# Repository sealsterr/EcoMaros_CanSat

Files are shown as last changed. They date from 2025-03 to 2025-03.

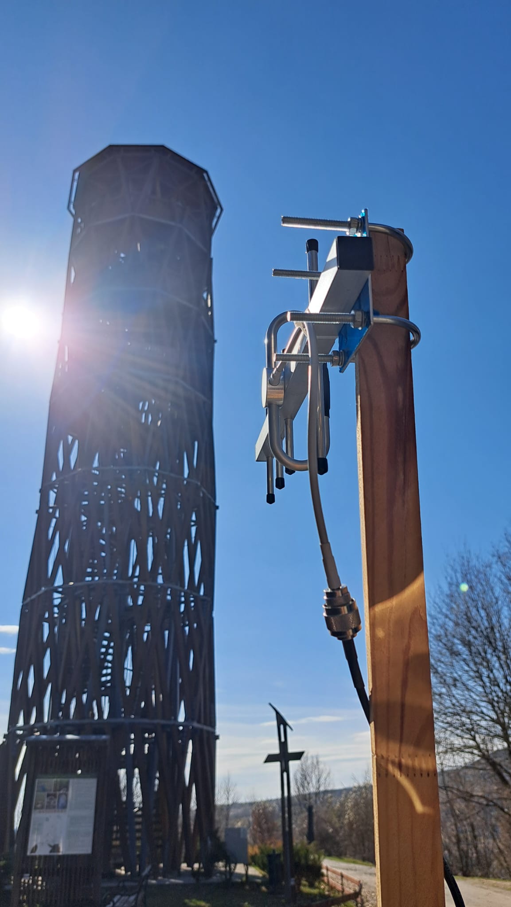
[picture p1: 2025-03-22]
Testing/final_test/image_5.jpeg

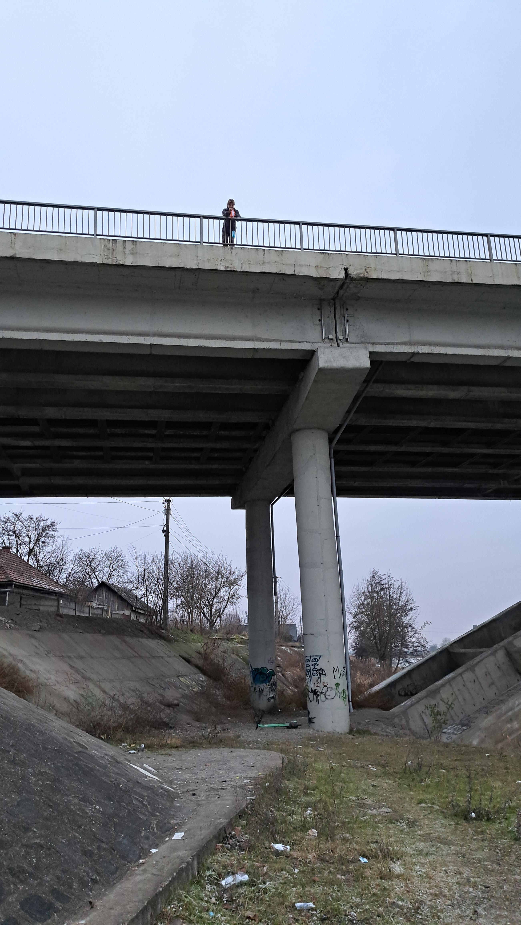
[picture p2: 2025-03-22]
Testing/parachute_test/20250118_162305(0).jpg

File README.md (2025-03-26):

# EcoMaros CanSat Project





Our team's project for the 2025 CanSat Hungary Competition.

## Table of Contents
- [Project Overview](#project-overview)
- [System Architecture](#system-architecture)
- [Hardware Components](#hardware-components)
- [Software Architecture](#software-architecture)
- [Testing](#testing)
- [Contributors](#contributors)
- [License](#license)

---

# Project Overview

## 🌍 Introduction
EcoMaros is a CanSat project developed for the European Space Agency’s CanSat competition. Our mission was to design, build, and launch a fully functional satellite the size of a soda can, carrying out both a **primary mission** (measuring atmospheric temperature and pressure) and a **secondary mission** (environmental air quality analysis).

Our CanSat was launched from a rocket, reaching an altitude of approximately **1 km** before descending via parachute while continuously transmitting data to our ground station. The data collected was analyzed to extract valuable scientific insights and improve future small-satellite designs.

## 🛠️ Mission Objectives

### ✅ **Primary Mission:**
- **Measure atmospheric temperature and pressure** throughout the descent.
- **Log and transmit real-time data** to the ground station.
- **Compare results with trusted meteorological sources** to ensure accuracy.

### 🌿 **Secondary Mission:**
- **Analyze air quality parameters** by measuring pollutants such as CO, CO₂, NO₂, and VOC levels.
- **Monitor altitude-based variations** in air quality and correlate with temperature/pressure.
- **Evaluate sensor efficiency** and compare with standardized environmental datasets.
- **Capture high-resolution video footage** during descent using an onboard camera, providing visual data to complement sensor readings and assist in post-mission analysis.

## 🛰️ Technical Summary

Our CanSat consisted of **three primary systems**:

1. **The CanSat** (the satellite itself):
   - Housed **sensors**, **microcontrollers**, and **power systems**.
   - Collected, processed, and transmitted environmental data.
   - Designed to survive high-G forces and impact upon landing.

2. **The Recovery System** (parachute):
   - Ensured **stable descent** for optimal data collection.
   - Tested under real-world conditions.

3. **The Ground Station** (communication and data reception):
   - Received **live telemetry** from the CanSat.
   - Used **LoRa communication** at 868 MHz.
   - Displayed data in **real-time dashboards** for analysis.

## 🔬 Innovation & Unique Features

- **Hybrid Communication System:** Combined LoRaWAN for real-time transmission with onboard SD card storage for redundancy.
- **Optimized Air Quality Sensor Placement:** Minimized contamination and external interferences.
- **Advanced Software Architecture:** Supported real-time data visualization and predictive modeling.
- **Robust Mechanical Design:** Impact-resistant casing, secure wiring, and heat-resistant materials ensured durability.

## 🚀 Development Phases

1. **Design & Planning:** Component selection, CAD modeling, and circuit design.
2. **Prototype Assembly:** Initial hardware integration and software development.
3. **Ground Testing:** Component-level and full-system tests, including **environmental, communication, and structural validation**.
4. **Flight Preparation:** Calibration, parachute testing, and mission simulations.
5. **Launch & Data Analysis:** Real-world deployment, telemetry collection, and post-flight analysis.

---

# System Architecture

The EcoMaros CanSat consists of multiple integrated subsystems, each playing a critical role in the mission. The architecture is designed to ensure efficient data collection, processing, and communication while maintaining structural integrity during descent.

## 🖥️ Block Diagram

The following diagram illustrates the overall architecture of the CanSat system, highlighting interactions between subsystems:

diagram

## 🛰️ Subsystem Overview

### 1️⃣ **Power Management System**
The CanSat operates using **two independent power sources**:
- **2000mAh 3.7V LiPo Battery:** Supplies power to the microcontroller, sensors, and radio transmitter.
- **1000mAh 3.7V LiPo Battery:** Dedicated to powering the onboard camera.
A **step-up voltage booster** (3.7V → 5V) ensures that the camera receives stable voltage for optimal performance.

**Key Features:**
- Dual power system ensures redundancy and extended operation time.
- Low-power microcontroller for optimized energy consumption.
- Integrated master switch to safely power the CanSat on/off.

### 2️⃣ **Microcontroller & Processing Unit**
The heart of the CanSat is the **Adafruit Feather M0 Adalogger**, which:
- Manages sensor data acquisition.
- Controls power distribution.
- Handles real-time telemetry transmission.
- Logs data onto the onboard SD card.

microcontroller

### 3️⃣ **Sensor Suite**
EcoMaros is equipped with a **diverse set of sensors** to ensure comprehensive environmental monitoring:

| Sensor | Function | Model |
|---|---|---|
| **Barometric Pressure & Temperature Sensor** | Measures altitude and air temperature | BMP280 |
| **Air Quality Sensor** | Detects pollutants (CO₂, NO₂, VOCs) | MQ135 |
| **Accelerometer & Gyroscope** | Measures orientation, tilt, and G-forces | MPU6050 |
| **GPS Module** | Tracks real-time location and altitude | DFRobot Gravity GNSS |
| **Camera** | Records footage during the mission | ESP32 CAM |

sensors
camera

**Data Collection & Processing:**
- All sensor data is processed **every 200ms** and stored in CSV format.
- In case of radio failure, the data is alos logged to an **onboard SD card** for post-flight analysis.
- The onboard motion-detecting camera captures video data separately.

### 4️⃣ **Communication System**
The CanSat transmits real-time telemetry data using an **RFM69HCW 868 MHz radio module**, connected to a **5 dBi dipole antenna**.

**Communication Flow:**
1. Sensor data is processed by the microcontroller.
2. Data packets are formatted and transmitted via the **RFM69HCW module**.
3. The **ground station receiver** decodes and logs incoming data.

**Key Features:**
- **LoRa modulation** for long-range, low-power data transmission.
- Configurable transmission frequency for interference mitigation.
- Ground station software displays real-time telemetry graphs.

radio

### 5️⃣ **Recovery System**
The CanSat is equipped with a **semi-spherical parachute** made of **ripstop nylon**, attached using a **tear-resistant tether system**.

**Parachute Deployment Sequence:**
1. The CanSat is ejected at **1000m altitude**.
2. The parachute deploys, slowing descent to **~7.5 m/s**.
3. The CanSat lands safely, with GPS data assisting in retrieval.

**Key Features:**
- **Metal hook attachment** for secure parachute connection.
- **Load-tested connection system** capable of withstanding **50N of force**.
- High-visibility **orange and white** color for easy retrieval.

Parachute System

---

# Hardware Components

This section provides a deep dive into the hardware components selected for the EcoMaros CanSat, explaining the rationale behind their choices and key specifications.

### 1️⃣ Main Board

*   **Component:** Adafruit Feather M0 Adalogger
*   **Microcontroller:** ATSAMD21G18 ARM Cortex M0+
*   **Key Features:**
    *   **Low Power Consumption:** Essential for extending mission duration. Operates efficiently, maximizing battery life.
    *   **Integrated SD Card Interface:** Allows for reliable onboard data logging, critical as a backup and for post-flight analysis.
    *   **Arduino IDE Compatibility:** Simplifies software development and debugging.
    *   **Compact Form Factor:** Fits well within the CanSat's size constraints.
*   **Role:** The central processing unit, managing all sensor data acquisition, processing, and transmission. It controls power distribution and ensures synchronized operation of all subsystems.

### 2️⃣ Sensors

*   We selected the following sensors for our primary and secondary missions:

    *   **2.1 Barometric Pressure and Temperature Sensor (Primary Mission):**
        *   **Component:** BMP280
        *   **Key Features:**
            *   **High Accuracy:** Provides precise altitude and temperature readings, crucial for primary mission objectives.
            *   **Low Power Consumption:** Minimizes impact on battery life.
            *   **Small Size:** Facilitates easy integration into the CanSat's limited space.
        *   **Role:** Measures atmospheric pressure and temperature during descent, providing key data for altitude determination and weather analysis.

    *   **2.2 Air Quality Sensor (Secondary Mission):**
        *   **Component:** MQ135
        *   **Key Features:**
            *   **Broad Spectrum Detection:** Detects a wide range of air pollutants, including NH3, NOx, alcohol, benzene, smoke, and CO2.
            *   **Analog Output:** Simple interface for easy data acquisition.
        *   **Role:** Monitors air quality during descent, providing insights into environmental conditions.
     
    *   **2.2 ESP32-CAM (Secondary Mission):**
        *   **Component:** AI-Thinker ESP32 CAM
        *   **Key Features:**
            *   **Integrated Camera:** Enables high-resolution video capture during descent.
            *   **Standalone Operation:** Functions independently of the main microcontroller for increased reliability.
            *   **Onboard Storage:** Stores video data on a dedicated SD card.
        *   **Role:** Captures visual data to complement sensor readings, providing a visual record of the CanSat's descent and the surrounding environment.
        *    **Features** It also uses **motion detection** to store only the necessary data

    *   **2.3 Accelerometer and Gyroscope:**
        *   **Component:** MPU6050
        *   **Key Features:**
            *   **6-Axis Measurement:** Provides comprehensive motion tracking data.
            *   **Digital Output:** Easy interface with the microcontroller.
            *   **Low Power Consumption:** Ensures minimal drain on the power supply.
        *   **Role:** Measures acceleration and angular velocity, providing data on the CanSat's orientation and stability during flight.

    *   **2.4 GPS Module:**
        *   **Component:** DFRobot Gravity GNSS
        *   **Key Features:**
            *   **High Sensitivity:** Enables accurate location tracking.
            *   **Compact Size:** Integrates easily into the CanSat.
        *   **Role:** Provides real-time location data, crucial for recovery after landing.

### 3️⃣ Communication Systems

*   **Component:** RFM69HCW 868 MHz Radio Module
*   **Key Features:**
    *   **LoRa Modulation:** Provides long-range, low-power communication.
    *   **Configurable Frequency:** Allows for adjustment to avoid interference.
    *   **Compact Size:** Facilitates integration into the CanSat.
*   **Role:** Transmits telemetry data to the ground station, enabling real-time monitoring of sensor readings.
*    **Antenna:** A custom-designed dipole antenna ensures reliable data transmission.
     *   **Key Features:**
        *   **5 dBi gain**: Enables optimal operation
        *   **868Mhz freq**: Ensures long-range, low-power communication with Ground Control

*   To ensure reliable and redundant power, we utilize a dual-battery system:

    *   **4.1 Main Battery:**
        *   **Type:** LiPo
        *   **Capacity:** 2000mAh
        *   **Voltage:** 3.7V
        *   **Role:** Powers the microcontroller, sensors, and radio module.
    *   **4.2 Camera Battery:**
        *   **Type:** LiPo
        *   **Capacity:** 1000mAh
        *   **Voltage:** 3.7V
        *   **Role:** Powers the onboard camera, providing independent power for image capture.
*   A **Step-Up Voltage Booster** is used to ensure that the onboard camera receives stable voltage for optimal performance.

### 5️⃣ Recovery System - Parachute

*    A **Metal Hook** is used to connect the CanSat with the parachute, ensuring the safety and durability of the tether
*    The CanSat is equipped with a **semi-spherical parachute** made of **ripstop nylon**. It is attached using a **tear-resistant tether system**, capable of withstanding up to 50N of force.
  *   **Key Features:**
       *   **Orange and white** for high visiblity

---

# Software Architecture

## 💻 Microcontroller Code 

The firmware running on the microcontroller handles sensor data acquisition, processing, and transmission. Key functionalities include:
- Initialization of sensors and communication protocols.
```c
  void setup() {
    Serial.begin(9600);
  
    // initialize modules
    init_radio_module();
    init_bmp_module();
    init_mpu_module();
    init_mq_module();
    init_sd_card();
    init_gnss_module();
  }
```

- Real-time data acquisition and processing
```c
sensors_event_t a; // m/s^2
sensors_event_t g; // rad/s
sensors_event_t temp; // C

mpu.getEvent(&a, &g, &temp);

sTim_t date = gnss.getDate(); // Date
sTim_t utc = gnss.getUTC(); // UTC Time
sLonLat_t lat = gnss.getLat(); // Latitude
sLonLat_t lon = gnss.getLon(); // Longitude
double high = gnss.getAlt(); // Altitude - m
double cog = gnss.getCog(); // Course over Ground - Degrees
double sog = gnss.getSog() * 0.514; // Speed over Ground - m/s

float temperature = bmp.readTemperature(); // C
float pressure = bmp.readPressure() / 100; // hPa
float altitude = bmp.readAltitude(1015.24); // m
float airquality = analogRead(11); // PPM

float gforce = sqrt((a.acceleration.x * a.acceleration.x) + (a.acceleration.y * a.acceleration.y) + (a.acceleration.z * a.acceleration.z)) - 11;
// after testing we found that during a state of rest the sensor measured 11G's, so
```

- Transmission of telemetry data
```c
String packet_str = "";
packet_str.concat(String(String(packetnum, DEC) + ","));
packet_str.concat(String(lat.latitudeDegree, 6) + ",");
packet_str.concat(String(lon.lonitudeDegree, 6) + ",");
packet_str.concat(String(high, 1) + ",");
```

## 📡 Ground Station Software

The ground station software receives telemetry data and prints it on the Serial Monitor, adding an additional RSSI value.
```c
// print received data with added RSSI value
buf[len] = 0;

Serial.print("$");
Serial.print(rf69.lastRssi(), DEC);
Serial.print(",");
Serial.print((char*)buf);
Serial.print("\r\n");
```

## 📊 Data Processing

Data is stored in a `DATALOG.txt` file, every line representing a value, with a comma as separator. This enables us to use Microsoft Excel to organise data in a more friendly environment, making it compatible with our **Ground Processing Software**.

- CanSat measurement format
  ```
  Packet Number, Date, Time, Course over Ground, Speed over Ground, Temperature, Pressure, Air Quality, Latitude, Longitude, GPS Altitude, Accelerometer X-Y-Z & Gyroscope X-Y-Z, G-Force, BMP Altitude
  ```

- Telemetry format:
  ```
  RSSI, Packet Number, Latitude, Longitude, GPS Altitude
  ```

- Ground Processing Software:\
  In order to visualise and interpret incoming and stored data, our team decided to use [Serial Studio](https://github.com/Serial-Studio/Serial-Studio). This program enables us to record, replay and store incoming data, making post-launch data analysis much easier to conduct. During Serial Studio setup, we have to specify which "preset" we want to use. We have created two custom JSON files:

  - `ground_station_live.json`
    - Used during the CanSat competition launch, designed to receive and visualise telemetry data.\
  code1

  - `ground_station_playback.json`
    - Crucial for documentation and post-launch data showcase.
    - Played a crucial role when presenting our measured data to the jury.\
  code2

# Testing

You can find additional images, videos, and graphs in the `Testing` folder within the main project repository.

## 1. 📶 Frequency Test

**Purpose:** To verify that the RFM69HCW radio module transmits within the designated 868 MHz ISM band, ensuring compliance with regulations.
*   **Procedure:**
    *   Connect the CanSat to a power source and activate telemetry transmission.
    *   Use a spectrum analyzer (Rigol DSA815) to capture the transmission spectrum.

*   **Expected Results:**
    *   Transmission centered precisely at 868.000 MHz, confirmed by the captured spectrum using the Rigol DSA815 Spectrum Analyzer.
    *   The captured spectrum confirms that our transmission is centered precisely at 868.000 MHz, with the signal strength peaking at -21.59 dBm, well within the acceptable limits for ISM-band operations
    *   The noise floor remains low, ensuring clean and stable communication
*   **Status:** Successful ✅
    freq_test_C

## 2. 🏋️‍♂️ Load Test

**Purpose:** To ensure the parachute attachment point can withstand the forces experienced during deployment and descent.
*   **Procedure:**
    *   Attach the parachute to the CanSat.
    *   Connect the parachute tether to a weight equivalent to 5 kg
    *   Suspended the weight for an extended period while inspecting for any signs of material fatigue, deformation, or failure

*   **Expected Results:**
        *   The parachute attachment securely held the load without any visible weakening, ensuring that it will perform reliably under real launch conditions
*   **Status:** Successful ✅

## 3. Temperature & Pressure Sensor Test
**Purpose:** Validate accuracy of the BMP280 measuring unit.
*   **Procedure:**
    *   Power on the CanSat, including the BMP280 sensor
    *   Log initial measurements to textfile
    *   Compare its readings with established weather data, sourced from reputable meteorological websites

*   **Expected Results:**
    *   Values aligned within an acceptable margin of error, confirming the sensors' calibration and accuracy.

*   **Status:** Successful ✅

 Date     | Time     | Temperature (°C) | Pressure (hPa) | External Temp (°C) | External Pressure (hPa) |
 -------- | -------- | --------------- | --------------- | -------------------- | ----------------------- |
 2025-03-20 | 10:00:00 | 22.5            | 1012.3          | 22.0                 | 1012.0                |
 2025-03-20 | 10:00:10 | 22.6            | 1012.4          | 22.0                 | 1012.0                |
 2025-03-20 | 10:00:20 | 22.7            | 1012.5          | 22.1                 | 1012.1                |

## 4. 📸 Camera Test

**Purpose:** To evaluate the performance and stability of the ESP32, by taking multiple tests in different scenarios.
*   **Procedure:**
    *   Moving up and down the stairs, in order to simulate real-time CanSat movement
    *   Mount ESP32 Cam module to the CanSat, and recording the footage
    *   Analyzing the footage, is it clear and without interruptions
*   **Expected Results:**
    *   The camera effectively handled vibrations and sudden shifts
    *   The camera operated continuously within the expected mission duration, without overheating or interruptions.
*   **Status:** Successful ✅

[YouTube link](https://www.youtube.com/watch?v=rytZMgvs1aI)

## 5. 💨 Air Quality Sensor Test

**Purpose:** To verify the functionality and responsiveness of our air quality sensor. We conducted a controlled test by exposing it to varying air conditions and analyzing the received data, the test lasted 10 seconds.
*   **Procedure:**
    *   Place CanSat near exhaust source to simulate polluted conditions, and log all the data
*   **Expected Result:**
    *   Sensor data showed a response to the change, indicating a significant deviation from the baseline. Finally, we returned the CanSat to clean air, where the sensor readings gradually stabilized back to their initial values

*   **Status:** Successful ✅

airquality

## 6. 🪂 Parachute Test

**Purpose:** To evaluate the deployment and descent characteristics of our parachute system.

*   **Procedure:**
     * Pack parachute, packing the parachute in its folded and secured state to simulate real launch conditions
     * Throw CanSat from the sky, conduct a field test using an older 3D-printed dummy version of the CanSat
     *Upon release, the parachute successfully unfolded, stabilizing the descent and demonstrating the effectiveness of both the packing method and the attachment points, the parachute's deployment in real world conditions

*   **Status:** Successful ✅

  [YouTube link](https://youtu.be/ZkYDVDR--aM)

## 7. ⚙️ Acceleration Test
*   **Purpose:** Assess the structural integrity of the CanSat under high acceleration forces by using a power drill.
*   **Procedure:** Attach the CanSat to a power drill and spinning it at high speed for a specified duration. By measuring the number of rotations within a set time frame, we calculated the angular velocity
*   **Status:** Successful. ✅

  [YouTube link](https://youtu.be/aheQlWmyFRo)

---

# Contributors

>We want to extend our deepest gratitude to everyone who has supported and contributed to our project. Your dedication, hard work, and generosity have been invaluable, and we truly appreciate the effort and time you’ve invested. Without your help, this journey wouldn’t have been possible! ♥️

- **Werner Haraszti - Lico Mecatronic S.R.L.** - technological, financial and equipment support
- **Fuccaro Miklós** - AutoCAD software coaching, IT support

---

# License
This project is licensed under the MIT License - see the LICENSE file for details.

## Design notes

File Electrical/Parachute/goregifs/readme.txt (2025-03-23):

PRINTING OUT THE GORE PATTERN (.gif format)

There are probably a number of different software packages that can be
used to print out the gore patterns. I find that MS EXCEL works well
for this purpose and is simple to do.

The first step is to unzip the ".zip" file.
Use WINZIP for this purpose.
WINZIP will allow you to extract the .gif files. These are graphic
format files. 
 
In EXCEL, choose Insert/Picture/From file, then choose the appropriate
gif file. This will bring the graphics file into the spreadsheet.
 
Next, simply choose File/Print to print out the pattern. 
It will come out on a number of sheets. 

Assemble the pattern, then measure and compare the printed size 
to the "Actual pattern size" shown on the pattern. 
If it is different, simply scale it by choosing File/Page setup
and set the Scale as required.
This will be the ratio of "Actual pattern size" divided by the printed
pattern size that you measured.

Reprint the pattern, and check to confirm that the printed pattern is
in fact the correct size.

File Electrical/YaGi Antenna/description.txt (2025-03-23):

868MHz 915MHZ Yagi Antenna External Directional Outdoor Aerial High Gain 7dBi N-female for Repeater Booster Amplifier

Features:
High gain
Strong directionality
Strong anti-interference ability
Realize long-distance communication
Simple structure and easy disassembly
Lightweight and durable, easy to install
High cost performance

Specification:
Model:Yagi Antenna
UHF:806-896MHz / 902-928MHz
Gain:7dBi
Connector:N Female
Element:7
Beam width : H:48 V:40
SWR: ≤1.5
Impedance: 50 Ω
Max Power : 50W
Size : 430*190*60*mm
Polarization:Horizontao or Vertical
Lightning protection: DC grounding

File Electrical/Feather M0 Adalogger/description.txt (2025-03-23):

Feather este noua placa de dezvoltare de la Adafruit si, dupa cum sugereaza numele, este subtire si usoara, fiind creata sa devina ultimul standard pentru nucleele microcontrolerelor portabile. Adafruit Feather M0 Adalogger vine ca o abordare a unui datalogger Cortex M0 complet (sau cititor de date) cu USB si incarcarea bateriei integrate. Este un Adafruit Feather M0 cu suport microSD, in centrul Feather M0 aflandu-se un procesor ATSAMD21G18 ARM Cortex M0 cu frecventa de 48MHz si 3.3V tensiune logica, acelasi folosit in Arduino Zero. Chip-ul are 256K Flash (de 8 ori mai mult decat Atmega328 sau 32u4) si 32K RAM (de 16 ori mai mult). In plus, chip-ul vine cu USB integrat pentru abilitatea de programare si depanare USB-la-serial, fara sa necesite un chip ca FTDI.

Pentru a fi usor de utilizat in proiectele portabile, au fost adaugate un conector pentru baterii Li-Po de 3.7V si posibilitatea de incarcare a bateriilor. Nu ai nevoie, astfel, de baterie, pentru ca va opera foarte bine de la conectorul USB. Totusi, daca ai o baterie, poti sa o iei cu tine si sa reincarci prin USB. Feather va comuta automat pe alimentarea prin USB atunci cand aceasta este disponibila. De asemenea, bateria a fost legata printr-un divizor la un pin analogic ca sa poti masura si monitoriza voltajul si sa stii cand este nevoie sa reincarci.

Feather M0 Adalogger utilizeaza spatiul liber ramas pentru adaugarea unui microSD si un LED verde:

LED verde la pinul #8 pentru clipire
Suport card microSD pentru adaugarea spatiului de stocare dorit, pentru citire si scriere

Placa vine testata si complet asamblata, cu bootloader USB pentru utilizarea imediata cu Arduino IDE. De asemenea, primesti si header pentru lipire atunci cand vrei sa folosesti o placa breadboard. Bateria Li-Po, cardul microSD si cablul USB nu sunt incluse.

Specificatii:

Masoara 51mm x 23mm x 8mm fara headerele lipite
Greutate de numai 5.3 grame
ATSAMD21G18 @ 48MHz cu 3.3V logica/putere
256KB FLASH + 32KB RAM
Fara EEPROM
Stabilizator de 3.3V cu iesire varf curent de 500mA
Suport USB nativ; vine cu bootloader USB si depanare prin port serial
De asemenea, primesti o multime de pini - 20 pini GPIO
Interfata seriala, I2C, suport SPI
8 x Pini PWM
10 x Intrari analogice
1 x Iesire analogica de 10 biti (DAC)
Incarcator Li-Po de 100mA incorporat, cu LED indicator de stare
LED rosu la pinul #13 pentru clipire
Pin de alimentare/activare
4 orificii de montaj
Buton de resetare
Dimensiune: 22.8mm x 51.6mm x 8mm
Greutate: 5.3g

Linkuri:

Tutorial de utilizare
Descarcari: fisa produsului, schema, fisierele EagleCAD PCB si Fritzing
Tutorial afisaje MicroPython
Tutorial de utilizare ATSAMD21 SERCOM pentru mai multe porturi SPI, I2C si serial
Tutorial debug header pentru Feather [M0]

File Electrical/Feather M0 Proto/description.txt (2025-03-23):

Feather M0 Basic Proto - ATSAMD21 Cortex M0

Specificatii:

Dimensiuni: 51mm x 23 mm x 8mm
Greutate: 4,6 grame
ATSAMD21G18@ 48MHz cu logica 3.3V
256KB FLASH, 32KB de RAM
32.768 KHz cristal pentru generarea de ceas & RTC
Regulator 3.3V cu 500mA curent de iesire
Suport USB nativ, vine cu bootloader USB si depanare port serial
20 pini GPIO
Hardware Serial, I2C, SPI
Iesiri PWM pe toti pinii
6 x 12-bit intrari analogice
1 x 10-bit iesiri analogice (DAC)
Incarcator 100mA LiPo cu LED indicator de stare
LED rosu pe pinul 13 pentru uz general
4 gauri de montare
Buton de resetare
Link-uri:

Pagina Producatorului
Tutorial

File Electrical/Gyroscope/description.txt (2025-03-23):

Caracteristici tehnice:
Tensiune de alimentare: 3.3V - 5V (regulator LDO inclus);
Tensiune magistrală I2C: 3.3V (MAX);
Curent: 5mA;
Range programabil giroscop: ±250, ±500, ±1000, ±2000 o/s;
Range programabil accelerometru: ±2g, ±4g, ±8g, ±16g;
Interval măsurare temperatură: -40oC - +85oC;
Frecvență maximă I2C: 400kHz.
Dimensiuni: 20mm x 15mm.

Modulul conține un circuit integrat MPU-6050 cu accelerometru, giroscop și senzor de temperatură. Acesta comunică pe interfață I2C, având nevoie de doar 2 conexiuni. Fiecare dispozitiv ce folosește interfața I2C are propria adresă. MPU6050 poate selecta una din două adrese disponibile, legând pinul AD0 la GND sau VCC. Această conexiune este făcută de obicei pe placuța modulului. 

Este util în proiectele dumneavoastră ce au nevoie să detecteze mișcarea și intensitatea ei, cum ar fi jocuri, stabilizare de imagine, step counter.

Pentru a instala bibliotecile necesare utilizării modelului MPU6050 mergeți la pagina: http://cartearduino.ro/v1/link21.1.0

Utilizare împreună cu Arduino
Accesați folderul “Arduino”, iar de acolo descărcați în format ZIP folderele: I2Cdev si MPU6050. Instalați bibliotecile urmând instrucțiunile descrise în capitolul “Biblioteci în Arduino” (Sketch -> Import Library -> Add .ZIP Library...) și selectați fișierele voastre. După instalarea bibliotecilor puteți găsi un exemplu de program printre sketch-urile demonstrative oferite de Arduino, așa cum este ilustrat în imaginea 1 .

Modulul MPU6050 folosește protocolul I2C pentru a comunica cu plăcuța Arduino. Pinul INT poate trimite cereri de întreruperi plăcuței – MPU6050 va anunța astfel apariția unor evenimente speciale. Fiecare dispozitiv ce folosește interfața I2C are propria adresă. MPU6050 poate selecta una din cele două adrese disponibile, legând pinul AD0 la GND sau VCC. Această conexiune este făcută de obicei pe plăcuța modului. Montajul este figurat în imaginea 2. Pentru mai multe detalii, consultați fișa tehnică.

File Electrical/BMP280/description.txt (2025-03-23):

The GY-BMP280 module comes with BMP280 sensor, which is an environmental sensor with temperature, barometric pressure that is the next generation upgrade to the BMP085/BMP180/BMP183.
This sensor is great for all sorts of weather sensing and can even be used in both I2C and SPI.
This precision sensor is the best low-cost, precision sensing solution for measuring barometric pressure with ±1 hPa absolute accuracy, and temperature with ±1.0°C accuracy. Because pressure changes with altitude and the pressure measurements are so good, you can also use it as an altimeter with ±1 meter accuracy
Pin pitch: 2.54mm
Module size: 11.5mm*15mm

Electrical Specifications of GY-BMP280 Module
Model: GY-BMP280-3.3
Chip: BMP280
Power supply:  3V/3.3V DC
Peak current: 1.12mA
Air pressure range : 300-1100hPa (equi. to +9000…-500m above sea level)
Temperature range: -40 … +85 °C
Digital interfaces: I²C (up to 3.4 MHz) and SPI (3 and 4 wire, up to 10 MHz)
Current consumption of sensor BMP280: 2.7µA @ 1 Hz sampling rate

Brief about GY-BMP280 Module
The GY-BMP280 Barometer Sensor is a breakout board for Bosch BMP280 high-precision and low-power digital barometer. It can be used to measure temperature and atmospheric pressure accurately. It can be connected to a microcontroller with I2C.

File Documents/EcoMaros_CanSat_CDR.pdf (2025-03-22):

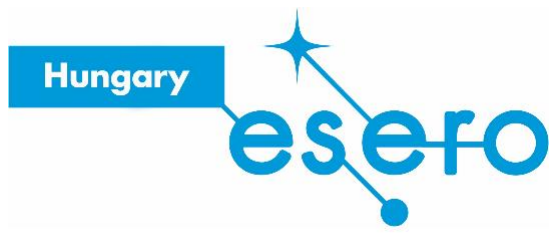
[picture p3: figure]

# Critical Design Review

# (CDR)

# Team: EcoMaros

# School Name & City: Bolyai Farkas

# Elméleti Líceum, Marosvásárhely

# Date: 2/16/2025

# Video link: https://youtu.be/EJZ_LCFnJKg

### Table of contents

### 1. INTRODUCTION

### 1.1. Introduction of the team

Our team is a dynamic group of three dedicated students from the Bolyai Farkas

Elméleti Líceum. Together, we bring diverse yet interconnected skills to the CanSat

project, building on a history of successful collaborations, such as participating in an

international Erasmus project. The team is guided by their experienced mentor, Veres

Péter, whose expertise in electronics and automation plays a crucial role in ensuring the

project's success.

Our mentor, Veres Péter is an engineer and amateur astronomer who provides

vital technical support throughout the project. His extensive background in electronics

and automation is key in guiding the team through testing and troubleshooting

processes. He dedicates approximately 8–10 hours per week to offering technical

advice for our team and helping resolve challenges, ensuring that every phase of the

CanSat project meets the competition’s requirements and rules, while also maintaining

high standards of reliability and precision.

Veres Ákos leads the team as the group coordinator and is in charge of the

hardware and software aspects of the CanSat. He is responsible for writing and

debugging our CanSat’s and Ground Station’s code, integrating circuits and sensors,

while also developing and maintaining the team’s website. His work is vital for

accommodating the project’s strict size and weight requirements while maintaining

functionality and reliability, taking into consideration the safety of our surroundings. Ákos invests roughly 10-15 hours per week in hardware development and integration,

continuously innovating to address technical challenges as they arise during testing.

Bedő-Tar Zerind oversees the design and overall appearance of our CanSat. His

creative vision ensures that the satellite is not only aesthetically pleasing but also

functionally robust, with careful attention to weight distribution and structural integrity

during both launch and landing phases. He’s also responsible for the visibility of the

satellite, ensuring an easier recovery after the successful mission. In his additional role

as social media manager, he manages the project's online presence, engaging with the

community and promoting our project to a broader audience. This includes status

updates on our official Instagram and Facebook accounts, blog posts on our website and physical interactions with friends and schoolmates. He allocates about 5 hours per

week to visual design tasks and social media activities, ensuring that both the physical

and digital presentations of the project are top-notch.

Koszta Gianluca-Krisztián is responsible for the design and implementation of the

parachute system that guarantees the safe descent of our CanSat. He performs detailed

aerodynamic testing and calculations to optimize flight performance and to meet the

competition’s specifications. He documents every technical and design aspect of the

project. This thorough documentation is essential for clear communication and future

reference. The majority of our team’s published images and posts exist thanks to his

restless efforts, following our tasks during every step of the competition. Krisztián

dedicates approximately 5-6 hours per week to developing the parachute system,

conducting aerodynamic tests, and preparing comprehensive project documentation.

### 1.2. Mission objectives

In addition to its primary objective, our CanSat incorporates a secondary mission

focused on environmental protection and visual data gathering. This mission was chosen

to address two key areas: improving air quality through precise environmental

monitoring and documenting landing and atmospheric conditions via visual recordings.

Together, these efforts contribute valuable data for environmental research and

community well-being, our team’s ultimate objective.

The first component of our secondary mission involves the collection of air quality

data during the CanSat’s descent. Our sensors are designed to measure various

atmospheric parameters, including pollutant concentrations and temperature variations,

which are critical indicators of air quality. The rationale behind this mission is to provide

actionable insights into local pollution levels and to support broader initiatives aimed at

reducing harmful emissions. By gathering and analyzing this data, the project seeks to:

- Measure and Examine: Monitor pollutant levels and ambient air conditions,

offering a snapshot of environmental health during the mission.

- Expected Outcome: Produce reliable data that can be used to assess the

impact of air pollution and inform strategies for cleaner air and improved

public health.

Complementing our environmental measurements, the CanSat is also equipped

with a side-mounted camera to capture quality video recordings of its surroundings

during descent. This visual data serves two primary purposes:

- Landing Documentation: To verify and document the performance of the

landing and recovery systems by recording the descent and touchdown.

- Environmental Context: To provide additional insights into the local

environment, correlating visual observations with sensor data.

For the CanSat launch to be considered successful with respect to the secondary

mission, the following objectives must be achieved:

- Accurate and Reliable Data Collection: The onboard sensors must consistently

capture precise air quality metrics throughout the mission, automatically

saving the measured data onto the onboard SD-Card.

- Effective Visual Documentation: The camera must record high-resolution

videos that clearly document both the landing process and the surrounding

environment, using it’s dedicated SD-Card as storage.

- Integrated Analysis: A thorough analysis combining sensor readings and

visual data should provide a comprehensive overview of the environmental

conditions during the mission.

### 2. CANSAT DESCRIPTION

### 2.1. Overview of the mission

The CanSat is designed to be launched on a rocket, reaching an altitude of

approximately 1,000 meters. At this altitude, the satellite will be ejected from the rocket

and will descend under the controlled deployment of a parachute system made out of

ripstop nylon, ensuring a landing speed of up to 10 m/s. During its descent, the satellite

will perform measurements related to both its primary objective (using the onboard

temperature and pressure sensor) and its secondary mission—which includes

environmental protection (through air quality monitoring with an air quality sensor) and

visual data collection (using an onboard camera). Telemetry data will be transmitted in

real time to the Ground Station using the radio communication module, while also

getting stored to the SD-card along with other values such as package number, date,

time, temperature, accelerometer and gyroscope data. Our CanSat is expected to

remain active for at least six hours to ensure it’s flight readiness during the competition.

(Figure 1)

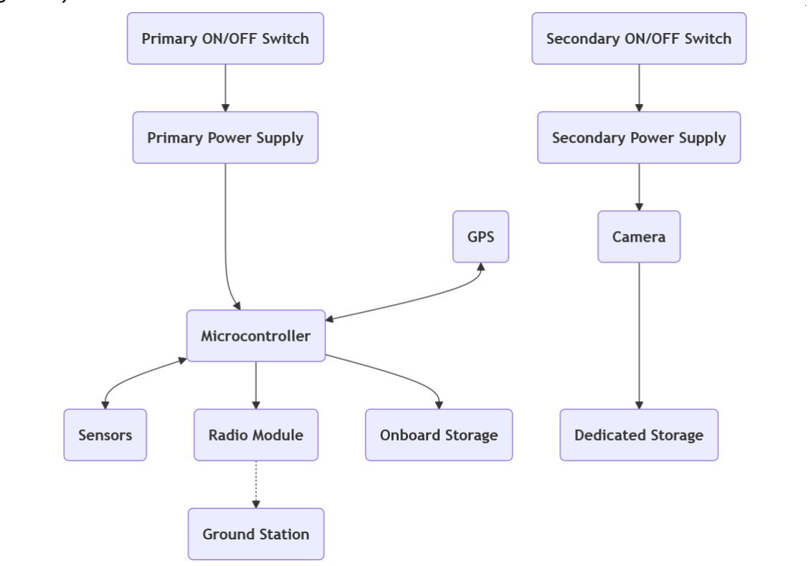
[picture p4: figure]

Figure 1

### 2.2. Mechanical/structural design

Our CanSat is built using bright orange PLA 3D printed plastic, chosen for its

excellent balance of lightweight properties, durability, and ease of fabrication. This

material not only provides high impact resistance but also offers the benefit of rapid

prototyping, allowing for quick design iterations. We have optimized the print settings

(high infill percentage, rounded corners and edges) to ensure the structure is both rigid

and capable of withstanding high-stress conditions during launch, descent, and landing.

Our design also includes screw holes on the body of the satellite. This integration allows

us to use small screws and fasteners to securely attach all internal modules and circuit

boards. This method not only provides a firm assembly but also reduces the reliance on

adhesives, ensuring each component remains tightly fixed throughout the mission.

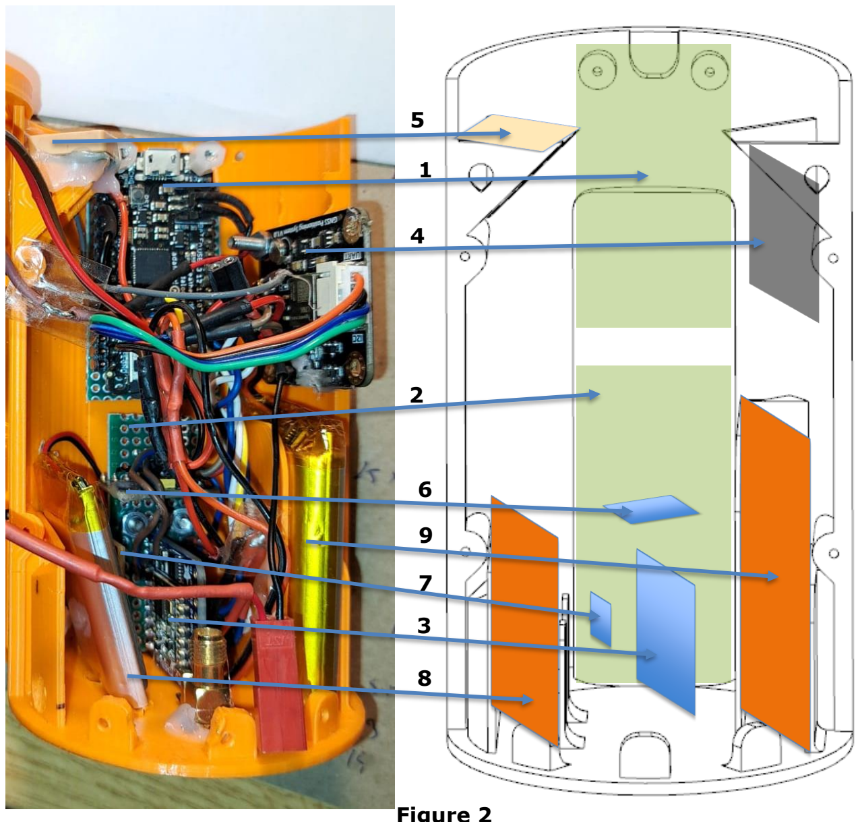
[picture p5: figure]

Figure 2

1. Feather M0 Adalogger with SD-Card support. It serves as the central

processing unit. It reads sensor data via the I2C bus, logs critical

information to the SD card, and manages power distribution effectively—

all while operating on minimal energy. It features an integrated connector

for a 3.7V LiPo battery and an onboard USB charging circuit, simplifying

the power management. This means you can easily power and recharge

the unit, which is crucial for mission reliability.

2. Motherboard used to interconnect all used boards: Radio module,

gyroscope, accelerometer, temperature and air quality sensors.

3. RFM69 HCW Radio Module used as digital radio module to communicate

with the Ground Station at 868 MHz, transmitting telemetry data.

4. DFRobot Gravity GNSS GPS Module receiver for GPS positioning and

altitude data.

5. GPS Antenna
6. MPU6050 | Gyroscope | and | accelerometer | sensor | measures

acceleration and gyroscopic movement on all three axis.

7. BMP280 temperature and pressure sensor, used for primary mission

objective.

8. LiPo 3.7V 1000mAh Battery Pack used to power the onboard camera

used for secondary mission.

9. LiPo 3.7V 2000mAh Battery Pack used as main power source for all the

other components of our CanSat. (Figure 2)

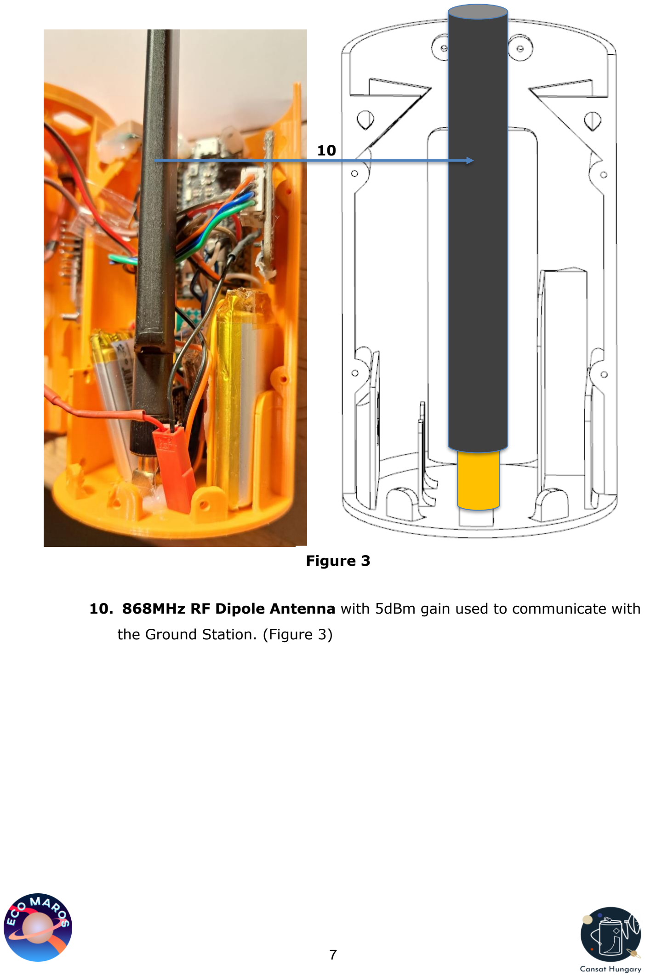
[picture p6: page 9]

10. 868MHz RF Dipole Antenna with 5dBm gain used to communicate with

the Ground Station. (Figure 3)

Figure 3

10

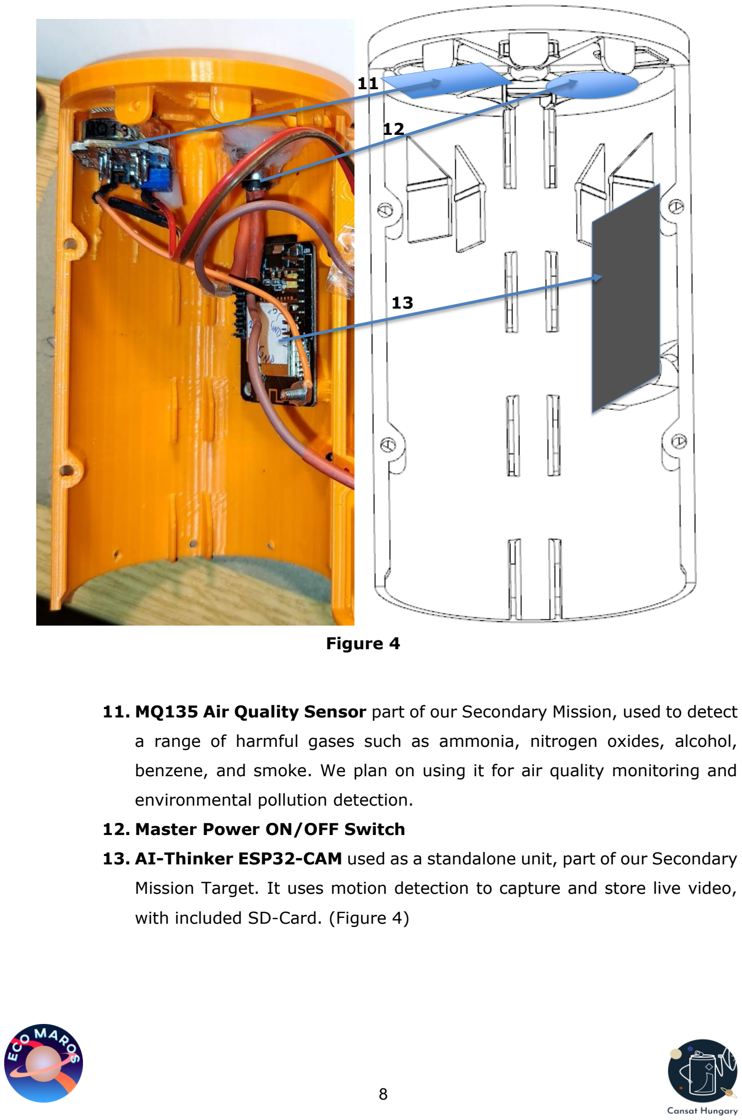
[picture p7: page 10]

### 11. MQ135 Air Quality Sensor part of our Secondary Mission, used to detect

a range of harmful gases such as ammonia, nitrogen oxides, alcohol,

benzene, and smoke. We plan on using it for air quality monitoring and

environmental pollution detection.

### 12. Master Power ON/OFF Switch

### 13. AI-Thinker ESP32-CAM used as a standalone unit, part of our Secondary

Mission Target. It uses motion detection to capture and store live video,

with included SD-Card. (Figure 4)

Figure 4

11

12

13

### 2.3. Electrical design

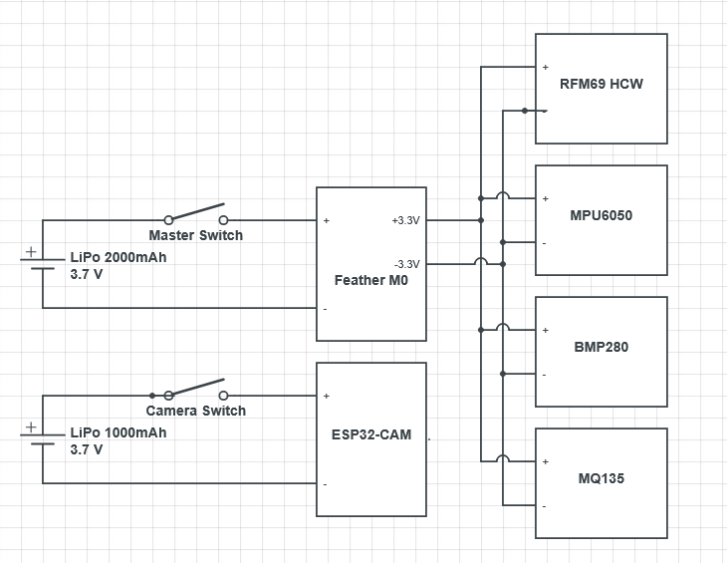
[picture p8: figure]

Component | Power consumption (mA / mW) | Component | Power consumption (mA / mW)
Adafruit Adalogger Feather M0 (3.7V) | 14 / 51.8 | ESP32-CAM (3.7V) | 150 / 555
BMP280 (3.3V) | 0.6 / 1.98
MQ135 (3.3V) | 29 / 95.7
Adafruit RFM69HCW 868MHz (transmitting) (3.3V) | 110 / 363
MPU6050 (3.3V) | 18 / 59.4
DFRobot Gravity GNSS (3.3V) | 40 / 132
Total | 210.6 / 703.88 | | 150 / 555

Figure 5

Table 1

CONCLUSION: For the boards and sensors we chose the LiPo 3.7V 2000mAh

Battery Pack and for the onboard camera we installed another LiPo 3.7V 1000mAh

Battery Pack. Both of them are capable of supplying enough power for the set minimum

mission time of 4 hours. (Figure 5 & Table 1)

RFM69HCW digital radio has an RF output power in 50 ohms, programmable

with 1dB steps: Max 20dBm. Capable of using high speed FSK modulation, up to 300

kb/s. Can be used in Packet mode or in Continuous mode. Due to mission characteristics

we will use it in Packet Mode. The packet (sensors and GPS data collected) is

automatically built with preamble, Sync word, and AES 128bit encoding. The reverse

operation is performed in reception.

We have chosen to use it just in transmitter mode from the CanSat to Ground

station - to send Telemetry data. The packages are sent 5 times each second. Frequency

usage will be determined on launch date with 100kHz scalability. We have tested it on

867.1 MHz as well on 867.5 MHz, with different RF power from 15dBm to 20 dBm

reaching fair level of receiving enough packages of data. (Figure 6)

The Ground Station uses the same radio module on the same frequency, only in

Receiver mode. With a personalized PC software we will follow telemetry with RSSI

value live and manually orientating the antenna toward the CanSat maintaining the

highest level of RSSI.

Conclusion: This module is capable of transmitting the amount of telemetry data

needed in desired time frame with enough radio power to satisfy our mission’s goal.

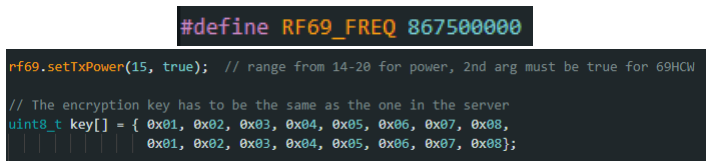
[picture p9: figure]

### 2.4. Software design

The EcoMaros CanSat software is designed as an integrated system to manage

all aspects of data handling—from acquisition to storage and transmission. Written in

C++ using the Arduino IDE.

1. Initialization phase: When powered on, the software initializes all components,

including the camera, GPS, sensor calibration, communication links, and onboard

memory.

2. Flight mode: Once the initialization phase is complete, the satellite runs in “Flight

mode” until shutdown.

Figure 6

In Flight mode the CanSat is in constant communication with our Ground Station

through it’s radio module and antenna, sending strings of telemetry data every ~200

milliseconds. Simultaneously, the satellite measures a set of different values using it’s

sensors with one decimal accuracy (except the latitude and longitude data, which

require 6 decimal places), and saves it into a datalog text file created on the SD-Card.

Each line, the data values are separated using commas, so the previously mentioned

datalog.txt file can be reformatted into an Excel CSV file, making Post Data Analysis

much less time consuming. Even if the radio communication breaks up, the CanSat will

continue to save data to it’s SD-Card, while checking for possible reconnection with the

Ground Station. The side camera is equipped with a motion sensing routine that

prevents the recording of static videos, making Post Data Analysis easier to conduct.

(Figure 7)

After touchdown, data such as temperature and air quality are continuously

measured and saved onto the board’s SD-Card, further contributing to data visualization

and comparative analysis, while maintaining radio communication with the Ground

Station for easier recovery (See section 2.6 for further details).

After multiple calculations, assuming that the CanSat will be measuring and

saving data for 4 hours, the result will be a 7 Mb data file, containing all the recorded

data (104 characters / reading, 5 readings / second, x60 / minute, x60 / hour, x4 / 4

hours = 7.488.000 characters).

## 104 x 5 x 60 x 60 x 4 = 7. 488. 000

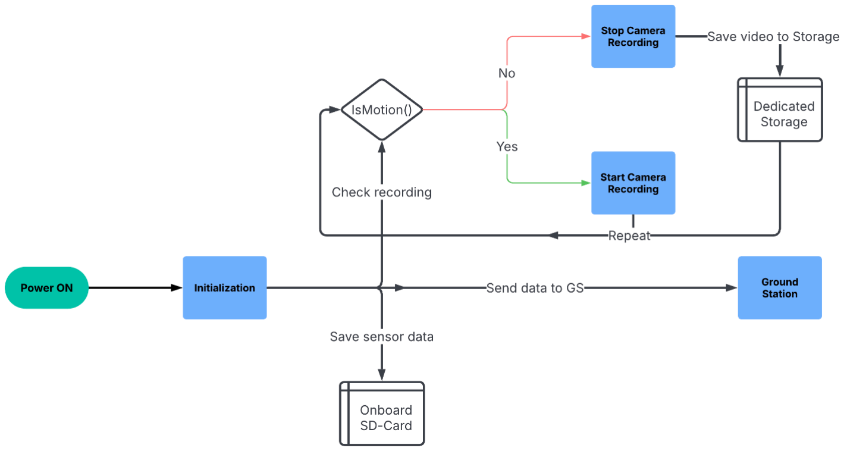
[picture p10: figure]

Figure 7

### 2.5. Recovery system

The recovery system of our CanSat is a parachute-based passive descent system,

designed to slow down the descent and ensure a safe landing.

The parachute is a lightweight, dome-shaped canopy made from durable

synthetic fabric. It consists of multiple stitched panels in orange and white, ensuring

visibility during descent. The seams are reinforced to provide structural integrity during

deployment.

The parachute is attached to the CanSat using elastic cords that are securely

looped through reinforced holes at the top of the canopy. These cords are fastened to

the main body of the CanSat using a metallic hook placed in the middle of our satellite’s

roof, ensuring a stable and controlled descent (under development). The attachment

method prevents excessive swaying and helps maintain a predictable landing pattern.

Once the CanSat is released from the rocket, the parachute unfolds due to air

resistance and the force of gravity. As the parachute inflates, it creates drag,

significantly reducing the falling speed. The controlled descent ensures a soft landing,

minimizing impact forces on the CanSat’s internal components.

Based on our most recent tests and calculations (Parachute Version 3.0), we

estimate the descent duration to be under 100 seconds, with a descent rate of 7.5 m/s.

depending on altitude, parachute size, and atmospheric conditions.

G = m ∗ g (force of gravity)

Fd = 0.5 ∗ cd ∗ ρ ∗ v

2
∗ A (drag force)

d = d1 − d2

A =

1
4

∗ π ∗ d

2

G = Fd

m ∗ g = 0.5 ∗ cd ∗ ρ ∗ v

2
∗ A

v

2 = m ∗

g
0.5

∗ cd ∗ ρ ∗ v

2
∗ A

m = 0.34 kg (mass of CanSat)

g = 9.81

m
s

2
cd = 0.78 (drag coefficient of paracℎute)

ρ = 1.225

kg
m³

(air density)

A = 0.124 m²
(total area of paracℎute)

d1 = 0.4 m (full diameter of paracℎute)

d2 = 0.04 m (top ℎole diameter of paracℎute)

v = √56.144 = 7.5

m
s

(descent rate of CanSat)

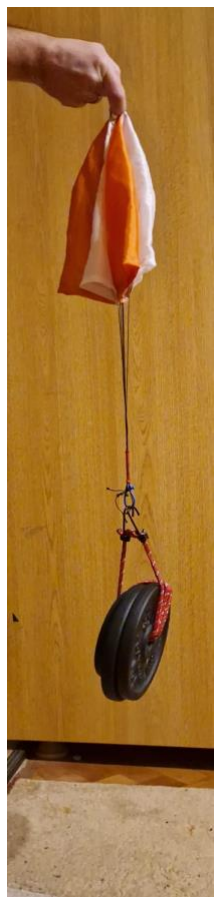
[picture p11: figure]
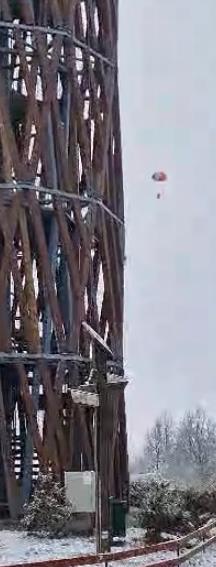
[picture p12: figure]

Parachute resistance test (50N)

&

Real flight test (26m)

### 2.6. Ground station

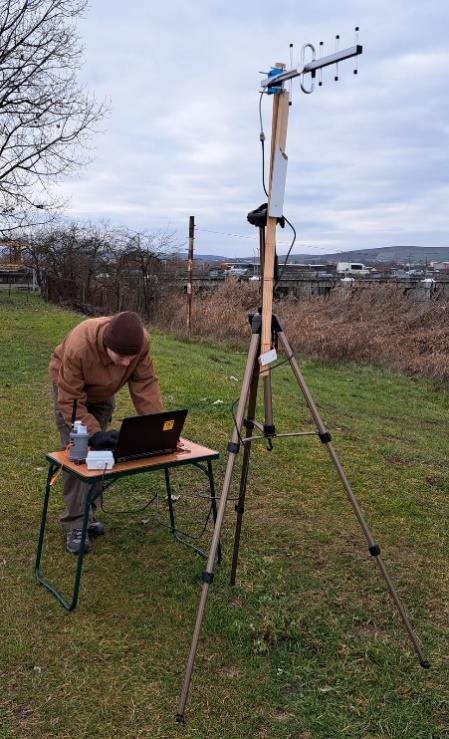
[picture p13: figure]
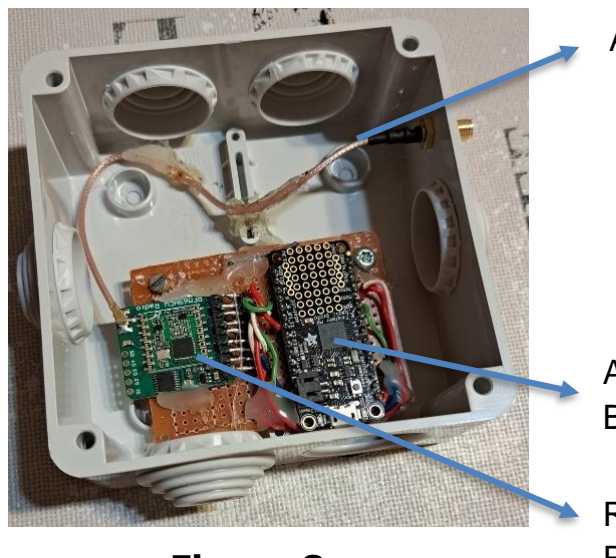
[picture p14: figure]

Antenna Connector

Adafruit Feather
Basic Proto

RFM69 HCW
Figure 8 | Radio Module

Figure 9

Our Ground Station consists of an Adafruit Feather Basic Proto microcontroller,

communicating with the laptop via USB. It has an RFM69 HCW Radio Module attached

to it, using a 5-element YaGi antenna to listen to the satellite’s telemetry transmissions.

(Figure 8 & 9)

We have developed a computer interface using Serial Studio JSON scripting to

continuously monitor telemetry data in real time received from our CanSat. It measures

the RSSI value, helping to orientate the ground antenna towards the direction of the

satellite. It has a crucial role in recovering the CanSat after touchdown, visualising the

flight path based on received telemetry data. (Figure 10)

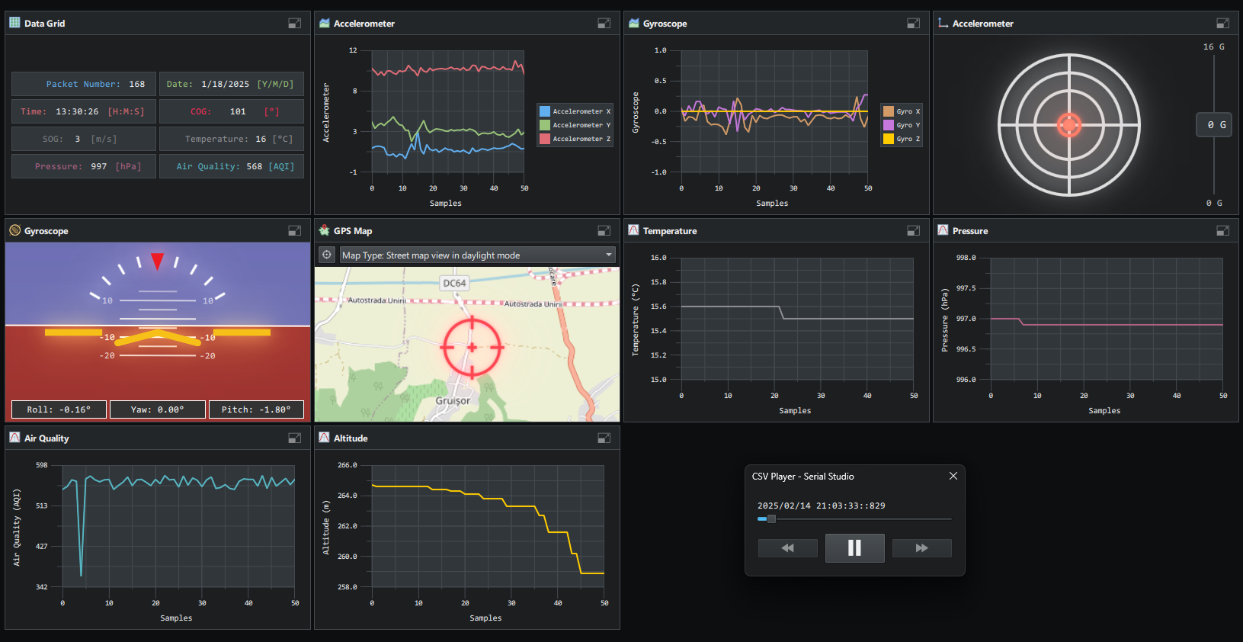
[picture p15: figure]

Figure 10

### 3. PROJECT PLANNING

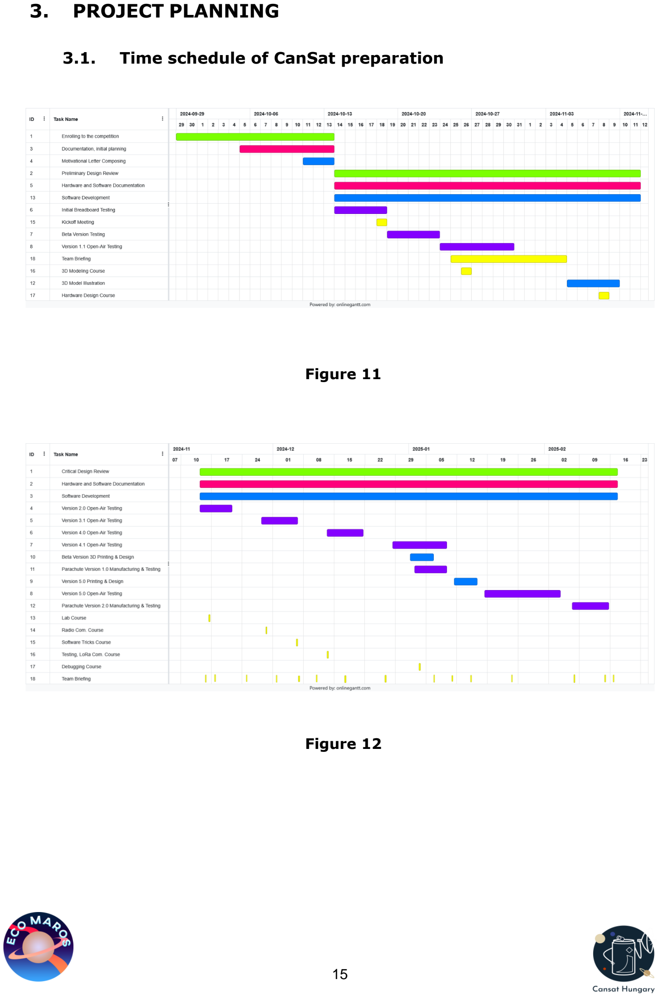
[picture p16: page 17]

### 3.1. Time schedule of CanSat preparation

Figure 12

Figure 11

### 3.2. Resource estimation

### 3.2.1. Budget

Components | Price (EUR)
Adafruit Adalogger Feather M0 | 19.00
BMP280 | 9.50
MQ135 | 12.38
Adafruit RFM69HCW 868MHz + antenna | 11.38 + 3.60
ESP32-CAM | 18.10
DFRobot GNSS GPS 1.0 | 17.05
8 Gb SanDisk Micro SD | 8.56
4 Gb SanDisk Micro SD | 4.75
LiPo 3.7V 2000mAh | 12
LiPo 3.7V 1000mAh | 8
3D materials + printing | 75
Master Switch | 1
MPU6050 | 4.7
TOTAL | 205.02

### 3.2.2. External support

During our journey, our team was lucky to receive support from multiple outside

sources. Haraszti Werner, the CEO of Lico Mecatronic S.R.L. provided us the

materials and tools needed for 3D printing the CanSat, donating six pieces of high-

quality circuit boards, two of which we integrated into the final CanSat body, leaving

the remaining 4 for testing purposes. Fuccaro Miklós offered individual assistance in

designing the satellite’s body, helping our team create the perfect match for our mission

by providing professional 3D design coaching using the AutoCAD software.

Table 2

### 3.2.3. Test plan

After many tests and unsuccessful attempts we have reached where we’re

confident that our CanSat can fulfil both the Primary and Secondary Missions. The best

communication results we have obtained in clear LOS at a distance of 3.7 km, with

15dBm TX power set, at 867.5 MHz frequency (all other frequencies worked also fine).

However, the parachute and drop tests are still undergoing, with additional

changes to be made in the future regarding the parachute.

### 4. OUTREACH PROGRAMME

At EcoMaros, our outreach strategy is designed to actively engage the

community and key stakeholders through our official channels. We ensure that our

platforms are regularly updated with fresh content ahead of the CDR submission date.

### 4.1. Existing Platforms and Future Plans

- Website: Our official website (ecomaros.space) serves as the central hub for

all EcoMaros project details, progress updates, and press releases. We plan

to enhance this platform with interactive blogs and multimedia content as

our project evolves.

- Instagram: Our Instagram page (www.instagram.com/ecomaros.cansat) (https://www.instagram.com/ecomaros.cansat?igsh=ODI4bWh4NG14cjJ2) is

actively maintained with behind-the-scenes images, project milestones, and

updates. Moving forward, we aim to deepen our community engagement

through regular posts and interactive stories.

Additionally, EcoMaros has developed a unique project logo, which is a key

element of our branding and outreach materials.

### 4.2. Summary of Outreach Activities

Platform URL

Outreach
Activities

Media
Coverage | Presentations/Exhibitions
ecomaros.space | - Regular EcoMaros
project updates -
Press releases -
Blog posts
- Active
outreach to
local media
- Presentations at local tech events and conferences

instagram.com/
ecomaros.cansat (https://www.instagram.com/ecomaros.cansat?igsh=ODI4bWh4NG14cjJ2)
- Frequent posting
of project
milestones - Sharing
behind-the-scenes
content -
Showcasing our
designed logo
- Monitoring
social
engagement
for media
interest
- Exhibition at local tech fairs (excluding school
events)

### 5. REQUIREMENTS

Characteristics | Quantity (unit) | Requirement | Eligible (Yes or No)
Height of the CanSat | 114 mm | 115 mm | Yes
Mass of the CanSat | 340 g | 300 – 350 g | Yes
Diameter of the CanSat | 65 mm | 66 mm | Yes
Length of the recovery system | 65x40 mm | 66x45 mm | Yes
Flight time scheduled | <100 s | 120 s | Yes
Calculated descent rate | 7.5 m/s | 5 - 12 m/s | Yes
Radio frequency used | 867.5 MHz | 868 MHz | Yes
Power consumption | 210.6 mA 150 mA | 210 * 4 h 150 * 4 h | Yes
Total cost | 205.02 Eur | 500 Eur | Yes

On behalf of the team, I confirm that our CanSat meets all the requirements set out in

the official guidelines for the 2025 Hungarian CanSat competition.

Signature, place and date:

Veres Péter

Marosvásárhely, 02.16.2025

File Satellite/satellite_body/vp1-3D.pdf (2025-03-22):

setPageBoxes("Crop", 0, 0, [0,2000,2000,0]);

# TITLE PART NO REVISION DESIGNER ENGINEER NOTES

THE INFORMATION AND/OR MATERIAL IN THIS DOCUMENT IS THE PROPERTY OF AND RESTRICTED INFORMATION AND/OR MATERIAL OF THE AUTHOR. THIS INFORMATION MAY NOT BE USED, REPRODUCED, PUBLISHED OR DISCLOSED TO OTHERS WITHOUT WRITTEN AUTHORIZATION. IT IS TO BE USED ONLY FOR MANUFACTURING ITEMS SPECIFIED WITHIN THE DOCUMENT.

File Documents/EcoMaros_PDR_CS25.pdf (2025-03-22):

# EcoMaros Előzetes tervfelülvizsgálat

# Tartalomjegyzék

1.Csapatunk bemutatása | 2
2. Ütemterv | 2
3. Küldetések áttekintése | 3
4. Kockázatok és várható nehézségek | 4
5. Mechanikai és szerkezeti tervezés | 4
6. Elektronikai tervezés | 5
6.1 Általános felépítés | 6
6.2 A másodlagos küldetés | 7
6.3 Energiaellátás | 7
6.4 Kommunikációs rendszer | 8
7. Szoftver | 8
8. Visszatérési rendszer | 9
9. Földi állomás | 9
10. Ismeretterjesztés és kommunikáció | 9

# 1. Csapatunk bemutatása

Az EcoMaros csapat három tagból áll, mindegyikünk különböző, de összefonódó területeken járul hozzá a CanSat projekt sikeréhez, kiemelkedő csapatdinamikával és erős együttműködéssel, amelyet korábbi közös projektek során is fejlesztettünk.

Elsőként Veres Ákos, a csapatkoordinátor és hardverfelelős, aki az elektronikai és mechanikai komponensek tervezésére és megépítésére specializálódott. Ákos mély tudással rendelkezik az áramkörök, szenzorok és egyéb elektronikai eszközök világában, amely elengedhetetlen a CanSat műhold működéséhez. Eddigi tapasztalata lehetővé teszi számára, hogy hatékonyan integrálja a különböző hardveres elemeket, figyelembe véve a szonda kis méretét és súlyát, ugyanakkor biztosítva a megbízhatóságot és a funkcionalitást. A precizitás és a problémamegoldó készségek, amelyekkel rendelkezik, lehetővé teszik, hogy innovatív megoldásokkal reagáljon a felmerülő technikai kihívásokra.

Bedő-Tar Zerind a csapat design és külalak felelőse, akinek fő feladata, hogy a CanSat megjelenését megtervezze és a fizikai struktúra külső elemeit alakítsa ki. Zerind kreatív és vizuális megközelítése biztosítja, hogy a műhold esztétikus és egyben funkcionális legyen, figyelembe véve a súlyelosztást és a szerkezeti integritást, amelyek elengedhetetlenek a stabil működéshez. A design kidolgozása során törekszik az innovatív anyaghasználatra, hogy a szonda bírja a felszállás és a visszatérés során fellépő terheléseket. Zerind részletorientált megközelítése nemcsak az esztétikai, hanem a mechanikai szempontokat is figyelembe veszi.

Koszta Gianluca-Krisztián, a csapat harmadik tagja, az ejtőernyőrendszer tervezésével, az aerodinamikai optimalizálással és a dokumentálással foglalkozik. Krisztián különleges figyelmet fordít a visszatérési rendszer megtervezésére, amely biztosítja, hogy a CanSat biztonságosan vissza tudjon térni a földre a küldetés befejeztével. Az ejtőernyő és az aerodinamikai elemzések pontos tervezése különösen fontos, hiszen ezek nélkülözhetetlenek a sikeres landoláshoz és az eszköz sértetlenségének megőrzéséhez. Emellett Krisztián felelős a dokumentációk elkészítéséért, gondoskodva arról, hogy a projekt minden technikai és tervezési aspektusa megfelelően le legyen írva, így könnyen érthető és bemutatható legyen.

Mentorunk, Veres Péter, mérnök és hobbicsillagász, aki szaktudását elektronikában és automatizálásban szerezte meg. Jelentős technikai támogatást nyújtott a projekt során, különös tekintettel az elektronikai elemekre és a tesztelésre, amelyek kulcsfontosságúak a CanSat megbízhatóságának és pontosságának biztosításában. Tapasztalatával és szenvedélyével nemcsak technikai tanácsokat ad, hanem inspirál és irányít minket, segítve a tervezési folyamat minden lépését a koncepció kialakításától egészen a végrehajtásig.

# 2. Ütemterv

- Ötletgyűjtés és előző projektek tanulmányozása (2 hét): A csapat korábbi sikeres CanSat projekteket elemez, hogy megértsék a technológiai és tervezési megoldásokat. Ákos a hardverfejlesztést, Zerind a szerkezeti stabilitást, Krisztián pedig a visszatérési rendszereket vizsgálja.
- Elméleti tudás megszerzése (3 hét): A csapattagok versenyképzéseken vesznek részt, hogy fejlesszék ismereteiket az elektronikáról, anyaghasználatról és aerodinamikáról. Ákos a szenzorok és kommunikációs rendszerek működését tanulmányozza, Zerind a szerkezetet, Krisztián pedig az ejtőernyőrendszereket.
- Tervezés (4 hét): A megszerzett tudás alapján részletes terv készül a CanSat szondához, amely magába foglalja a szerkezeti, elektronikai és aerodinamikai felépítést.
- Építés (3 hét): Az első prototípus megépítése során minden csapattag a saját részterületén dolgozik, miközben szorosan együttműködnek. Ákos az elektronikát, Zerind a külső burkolatot, Krisztián pedig az ejtőernyőrendszert fejleszti.

- Tesztelés (2 hét): Az elkészült prototípus tesztelése mentorunk segítségével. Ákos az elektronikai rendszereket, Zerind a szerkezetet, Krisztián pedig az ejtőernyőt teszteli.
- Hibaelhárítás (2 hét): A tesztelés során felmerült problémák javítása, minden csapattag a saját területén elemzi és javítja a hibákat.
- Újabb tesztelések (2 hét): Javított prototípus ismételt tesztelése, hogy meggyőződjünk a javítások sikerességéről.
- Tökéletesítés (1 hét): Az utolsó simítások, logók és szponzori matricák felhelyezése, végleges ellenőrzések a versenyre való felkészüléshez.
Csapattag(ok) | Feladat | Idő
Ákos, Zerind, Krisztián, Mentor | Ötletgyűjtés, tanulmányozás | 1-2 hét
Ákos, Zerind, Krisztián | Képzések | ~3 óra/hét
Ákos | Hardver + Szoftver | 6 óra/hét
Zerind | CanSat tervezése | 3 óra/hét
Krisztián | Visszatérési rendszer tervezése | 3 óra/hét

# 3. Küldetések áttekintése

Elsődleges küldetés:

Légnyomás és hőmérséklet

Az csapatunk projektjének célja, hogy pontos adatokat gyűjtsön a légnyomás és hőmérséklet alakulásáról a légkör különböző szakaszaiban. Ez az információ segít a légkör dinamikájának és az éghajlati folyamatok jobb megértésében, és támogatja a bolygókutatási kezdeményezéseket.

Másodlagos küldetés:

A) Környezetvédelem

Másodlagos küldetésünk fő célja a környezetvédelem támogatása, levegőminőségi adatgyűjtéssel. Az EcoMaros névhez híven a küldetés a légszennyezés csökkentésére és a tisztább levegő biztosítására irányuló kutatásokhoz járul hozzá, elősegítve az életminőség javítását.

B) Vizuális Adatgyűjtés

A CanSat az oldalába elhelyezett kamera segítségével rögzíti környezetét az ereszkedés során. Ez a vizuális adatgyűjtés a környezetvédelmi megfigyelések mellett a leszállás dokumentálását is támogatja.

Ha a körülmények megengedik, mindkét másodlagos küldetést megvalósítjuk.

# 4. Kockázatok és várható nehézségek

A CanSat projektünk során több kihívással is szembesültünk, amelyek megoldása hatékony stratégiát igényel.

Az egyik legnagyobb problémánk a CanSat tömeghatárának betartása, ezért úgy döntöttünk, hogy könnyű, praktikus anyagokat fogunk használni a szonda megépítéséhez. Ezzel biztosítjuk a szerkezet stabilitását is.

Az időbeosztás szintén nagy kihívást jelent számunkra. A projekt számos feladatot és határidőt követel meg, ezért a lemaradásainkat szorgalmas munkával pótoljuk, és a felesleges programokat lemondjuk, hogy a CanSat fejlesztésére tudjunk koncentrálni.

Emellett a 3D-nyomtatáshoz szükséges eszközök és technológiai háttér nem állnak rendelkezésünkre, ezért új szakmai kapcsolatokat szeretnénk kialakítani a megfelelő támogatás biztosítása érdekében. Ezekkel a megoldásokkal a csapat elkötelezetten dolgozik azon, hogy sikeresen elérje a projekt céljait, és eredményes CanSat küldetést valósítson meg.

Probléma | Megoldás
Tömeg | Könnyű és praktikus komponensek felhasználása, folyamatos mérések
Időbeosztás | Lemaradások bepótolása, fölösleges programok lemondása
3D Nyomtatás | Érdeklődés, új kapcsolatok kialakítása

A legelső éles teszt során a műhold és a földi állomás közti rádiókommunikációt teszteltük. Ez a próba eredménytelennek bizonyult, mivel kétszáz méter után megszakadt a kapcsolat a CanSat-tal. Csapatunk sokat tanult az esetből és több változtatást is kell végezzünk a modellen, többek között a vevőantenna kicserelése egy nagyobb jelszint vételezés érdekében. Ez a probléma kiküszöbölése után tudjuk a modul teljes fogyasztását kiszámolni, ennek függvényében kiválasszuk a megfelelő akkumulátor modellt.

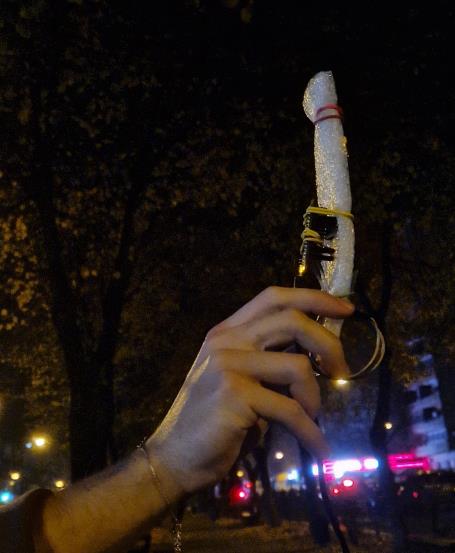
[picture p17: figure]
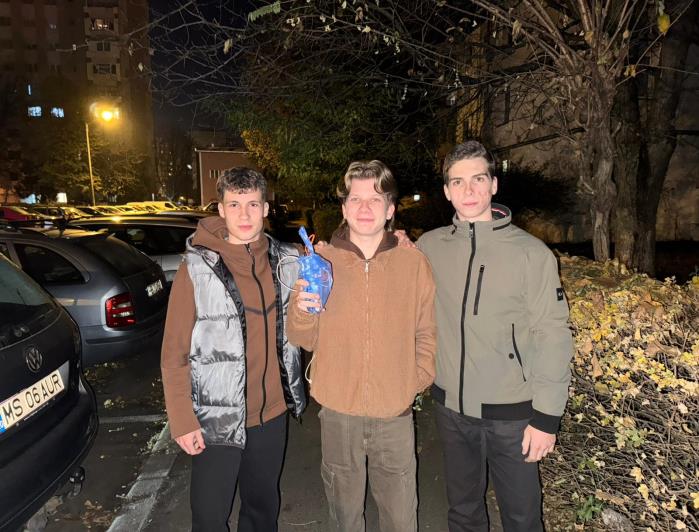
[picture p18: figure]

# 5. Mechanikai és szerkezeti felépítés

Más csapatok projektjeire alapozva úgy döntöttünk, hogy PLA 3D nyomtatáshoz alkalmas műanyagot fogunk használni a CanSat megvalósításához, emellett az ejtőernyő ripstop nájlonból fog készülni. A műhold belsejét szintekre osszuk, amelyek a CanSat különböző belső komponenseit fogják stabilan tartani és összekötni (3. ábra). Ezek az emeletek fém csavarokkal lesznek rögzítve a műhold többi részéhez. A súlyelosztás és a stabil ereszkedés érdekében a CanSat legalsó szintjére helyeznénk el az akkumulátort. A CanSat tetejébe és oldalába réseket alakítanánk ki az ejtőernyő, szenzorok, GPS, kapcsoló, és antenna számára.

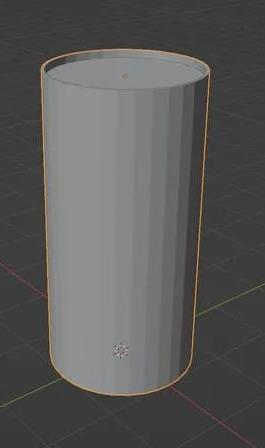
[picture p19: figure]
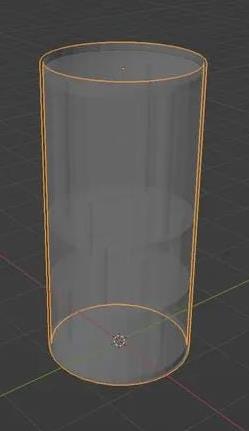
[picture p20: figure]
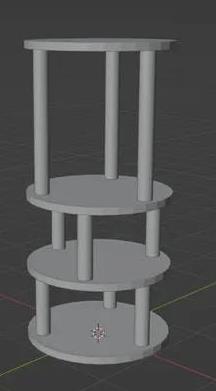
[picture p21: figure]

1. ábra | 2. ábra | 3. Ábra

# 6. Elektronikai felépítés

## 6.1 Általános felépítés

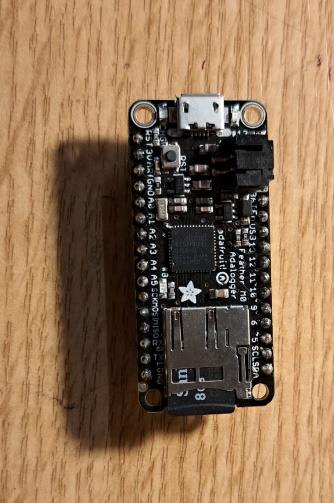
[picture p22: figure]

- A CanSat adatgyűjtő és rögzítő processzornak több modell kipróbálása után az Adafruit Adalogger Feather M0 modellre esett a választásunk, több ok miatt:
a. kis fogyasztás
b. beépített csatlakozó LiPo 3.7V-os akkumulátornak
c. beépített USB töltő áramkör az akkumulátornak
d. beépített Micro SD-kártya tok és illesztő áramkör
e. I2C Bus szenzorok olvasására
f. megfelelő mennyiségű portok száma
g. 3.3V-os tápfeszültség biztosítása a szenzoroknak és perifériáknak

- DFRobot Gravity GNSS GPS vevő modul

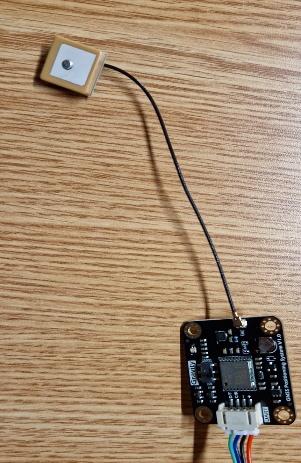
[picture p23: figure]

- BMP280 hőmérséklet és légnyomás szenzor

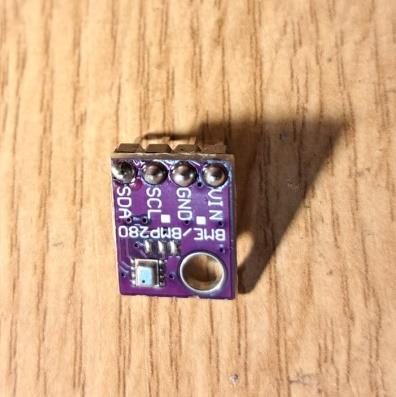
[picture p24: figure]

- MQ135 levegőminőség szenzor

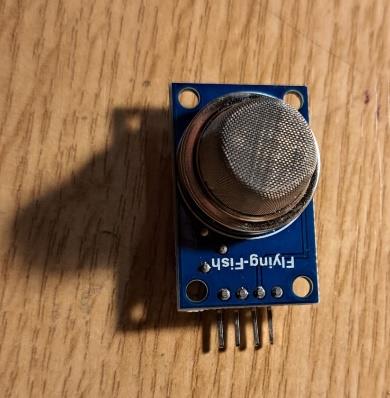
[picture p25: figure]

- Adafruit RFM69HCW 915MHz digitális rádiómodul

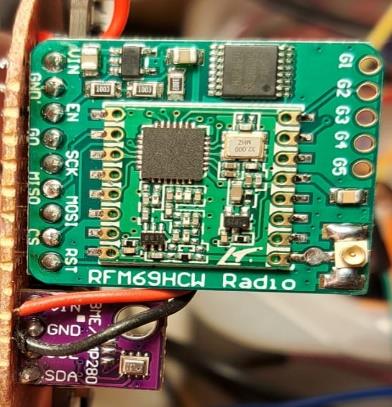
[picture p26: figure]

- 8 Gb SanDisk Micro SD kártya a Feather alaplapra adatrögzítés és tárolás érdekében
- ESP32-CAM kameramodul beépített SD kártyával


## 6.2 A másodlagos küldetés

A szenzorok által mért értékeket egymás után rendezve, vesszővel elválasztva, soronként küldjük ki a rádiómodulnak és írjuk ki az SD-kártyára biztonsági mentésként.

Idő, Karakterhossz, Vételjel szint (dBm), Mérés száma, Hőmérséklet (C), Légnyomás (HPa), Magasság (m), Levegőminőség index (PPM)


## 6.3 Energiaellátás

Az energiaellátást egy beépített LiPo akkumulátorral szándékozzuk megoldani. A modell kiválasztása folyamatban van. A töltést a Feather M0 biztosítja, ugyanúgy mint az üzemfeszültséget is.

ESP32-CAM által készített és mentett tesztfotó (Micro SD kártya)

Modell | Ár (USD) | Energiafogyasztás (mA)
Adafruit Adalogger Feather M0 | 19.95 | 14
BMP280 | 9.98 | 0.6
MQ135 | 12.99 | 150
Adafruit RFM69HCW 915MHz + antenna | 11.95 | 150
ESP32-CAM | 19 | 150
DFRobot GNSS GPS 1.0 | 17.90 | 40
8 Gb SanDisk Micro SD | 8.99 | -
4 Gb SanDisk Micro SD | 4.99 | -
LiPo akkumulátor | ? | -
Ejtőernyő | ? | -
3D nyomtatás | ? | -

## Összesen:

## - 105.75 $ (ehhez fognak adódni a további költségek)

## - 504.6 mA fogyasztás

## 6.4 Kommunikációs rendszer

A CanSat repülő modulban a fent említett Adafruit Adalogger Feather M0 -hoz illesztjük az RFM69HCW 915MHz frekvenciájú digitális rádiómodult. Az mért adatokat 300ms-ként küldjük ki rádiójel formájában és mentjük ki a MicroSD kártyára. Egyirányú kapcsolatra terveztük, az elküldött adatcsomagokat a földi bázis azután rögzíti, amiután létrejött a stabil rádiókapcsolat. Ezeket az adatokat sikeres földet érés után kimásoljuk és feldolgozzuk.

# 7. Szoftver

A komponensek programozására az Arduino IDE platformot használjuk, a nyert mérési adatok értelmezésére Excel görbéket fogunk generálni. Mivel minden mérésünk indexelve van soronként, az elvesztett mérési sorok biztonságosan tárolva maradnak a CanSat MicroSD kártyáján.

Előzetes számítás alapján minden adatsorunk 30 byte hosszúságú. Másodpercenként három csomagot mérünk, tárolunk és sugárzunk. ~0.3MB / hr. A GPS modulból nyert helyzetlokalizációs adatok továbbsugározásakor az adatsor 50 byte-ra bővül, ez adat alapján a modul 0.5MB / hr tárhelyet fog megtölteni.

A verseny későbbi szakaszaiban fennáll az adatsor további bővítése. Mivel a küldetés 4 óra hosszú lehet maximum, a mért adatok elférnek a SD kártyán.

A kameramodul másodpercenként egy képet készít bekapcsolás után 1600x1200x24 BPP felbontással és 144 KB mérettel (~518MB / hr). Nem sugározzuk rádión, csak az SD kártyán tároljuk. Négy órás küldetéssel számolva a készített fényképek elférnek az SD kártyán.

# 8. Visszatérési rendszer

Elképzeléseink szerint a CanSat visszatérési rendszere egy hexagonális ejtőernyő lesz, ami jelenleg tervezés és tesztelés alatt áll.

# 9. Földi állomás

A földi állomás magába foglalja az Adafruit Feather M0 Basic mikroszámítógépet és egy Adafruit RFM69HCW 915MHz digitális rádiómodult a hozzá csatlakoztatott antennával. Ez a komponens is Arduino IDE segítségével van beprogramozva, emellett a bejövő adatokat a PuTTY soros port monitorizáló program segítségével mentjük el egy .csv fájlba. Laptopot szándékozunk használni, USB kábel segítségével kommunikálunk a földi modullal. A rádiójel megszakadása esetén a hiányzó adatokat tudjuk pótolni a CanSat modul SD kártyájáról. Ideális esetben 100%-os lesz a vételezett adatcsomagok mennyisége.

# 10. Ismeretterjesztés és kommunikáció

Az EcoMaros csapat számára kiemelten fontos a projekt során szerzett tapasztalatok és eredmények megosztása. Ennek érdekében több közösségi média platformot is használunk, hogy elérjük a különböző érdeklődési körű közönségeket, bemutatva munkánkat és inspirálva a következő generációt.

Elsődleges kommunikációs platformunk az Instagram, ahol rendszeresen megosztjuk a projekt különböző fázisait, a tervezési és építési folyamatok mögötti technikai részleteket, valamint a tesztelések során szerzett tapasztalatainkat. Ezeket a posztokat gondosan szerkesztett képekkel és informatív leírásokkal kísérjük, hogy a barátaink, családtagjaink, valamint a tudományos érdeklődésű közönség is megismerhesse fejlődésünket.

A Facebook oldalunk bővebb bejegyzésekkel és videós frissítésekkel szolgál majd, amelyeken keresztül a projekt összetettebb aspektusait is bemutatjuk. Ezen a platformon interaktív kapcsolatot építünk a követőinkkel, lehetőséget biztosítva számukra, hogy kérdéseket tegyenek fel, és betekintést nyerjenek a CanSat építésének és fejlesztésének folyamatába.

A projektünk sikeres befejezését követően tervezzük egy weboldal létrehozását, amely egy átfogó információs portálként fog működni. A weboldal részletes információkat tartalmaz majd a csapatunkról, a műhold technikai jellemzőiről, valamint a projekt során szerzett tapasztalatainkról. A weboldal segíthet abban, hogy tudományos közösségek, jövőbeli CanSat versenyzők és oktatási intézmények is hozzáférjenek a projekt részleteihez és inspirációt merítsenek belőle.

A kommunikációs csatornáinkat úgy alakítjuk ki, hogy azok hosszú távon is elérhetők maradjanak, így a CanSat verseny után is hozzájáruljunk a tudományos érdeklődés és a technológiai innováció iránti lelkesedés növeléséhez.

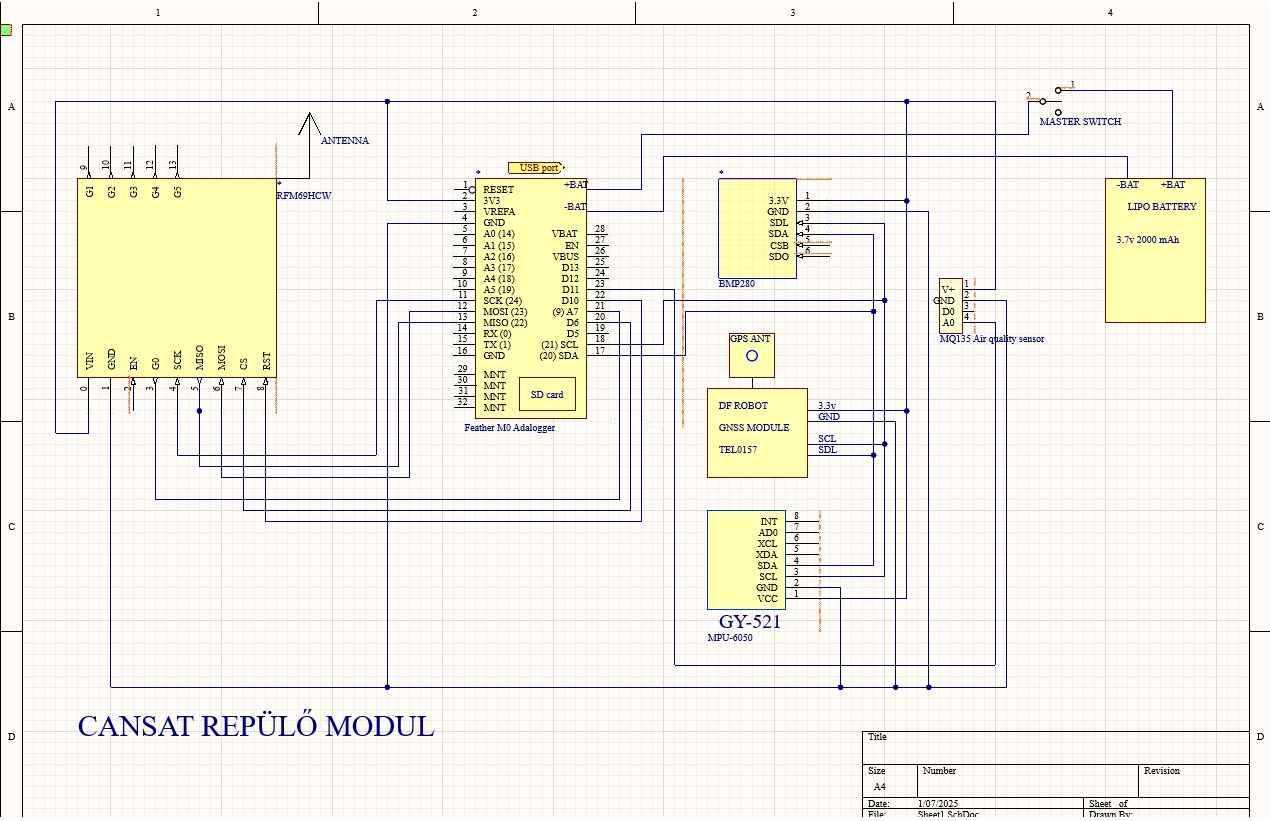
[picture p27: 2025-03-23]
Electrical/Schematics/Clipboard02.jpg

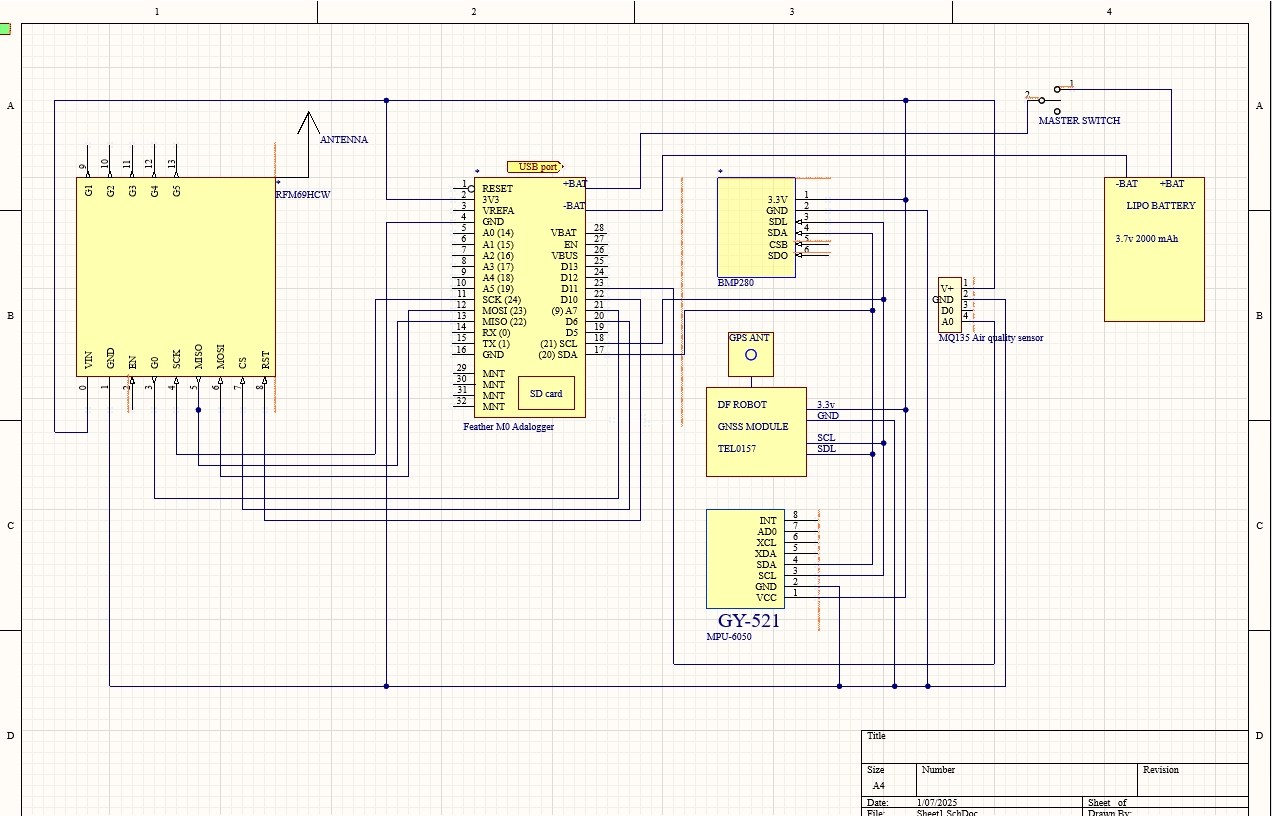
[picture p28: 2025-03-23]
Electrical/Schematics/Clipboard01.jpg

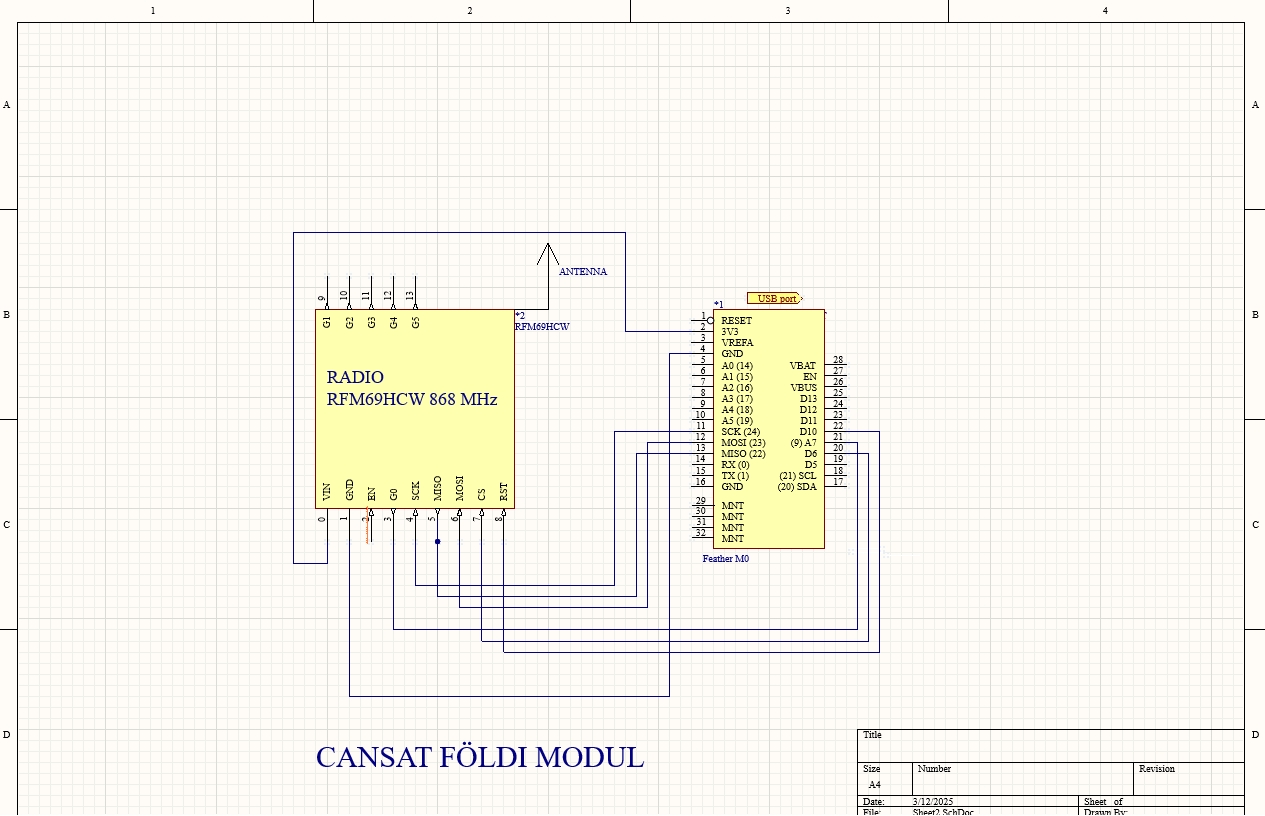
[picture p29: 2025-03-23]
Electrical/Schematics/New/Clipboard04.jpg

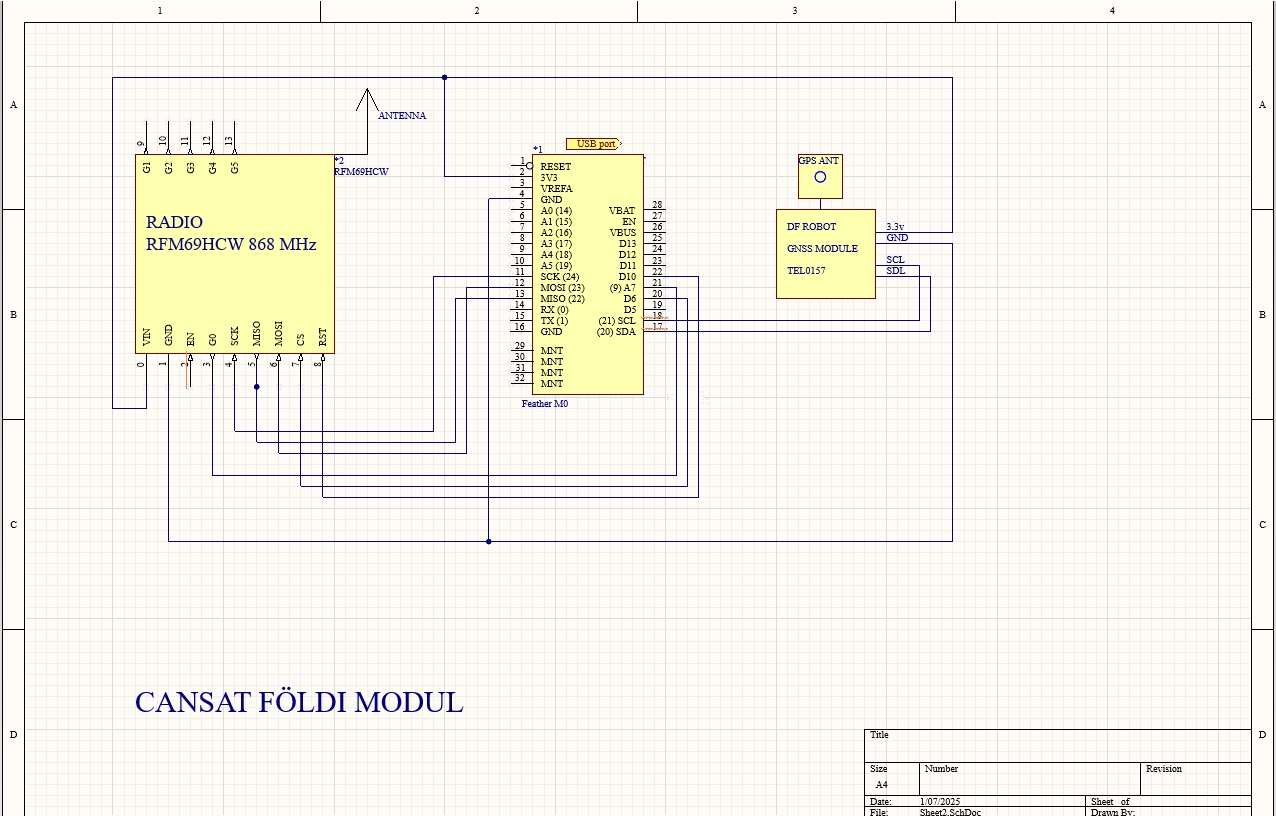
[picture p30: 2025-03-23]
Electrical/Schematics/Clipboard05.jpg

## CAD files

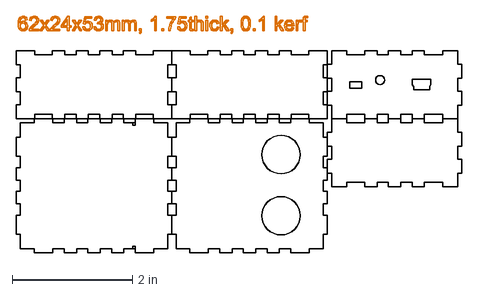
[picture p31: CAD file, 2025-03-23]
Electrical/RFM69HCW/RFM69-master/RFM69-master/Examples/SonarMote/SonarMote_lasercut plans_1.75mm acrylic.dxf
7.41 x 3.94 in

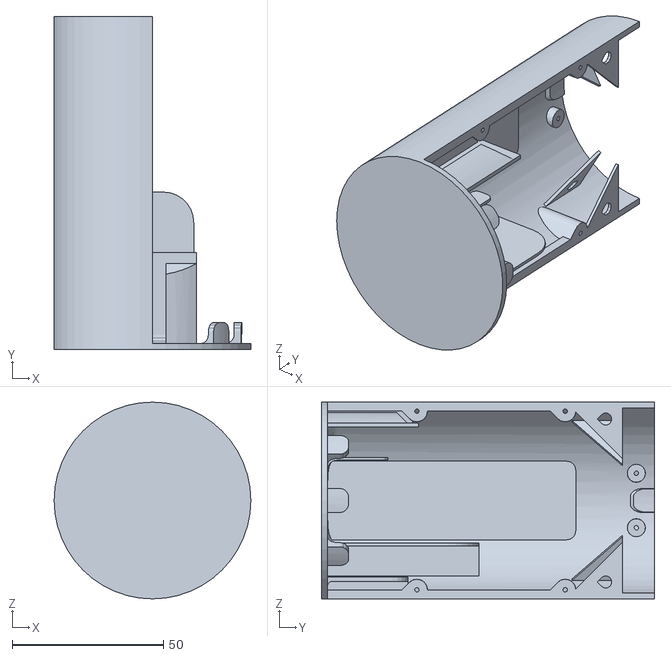
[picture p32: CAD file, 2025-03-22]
Satellite/satellite_body/vp2-v5.stl
65.0 x 110.0 x 65.0

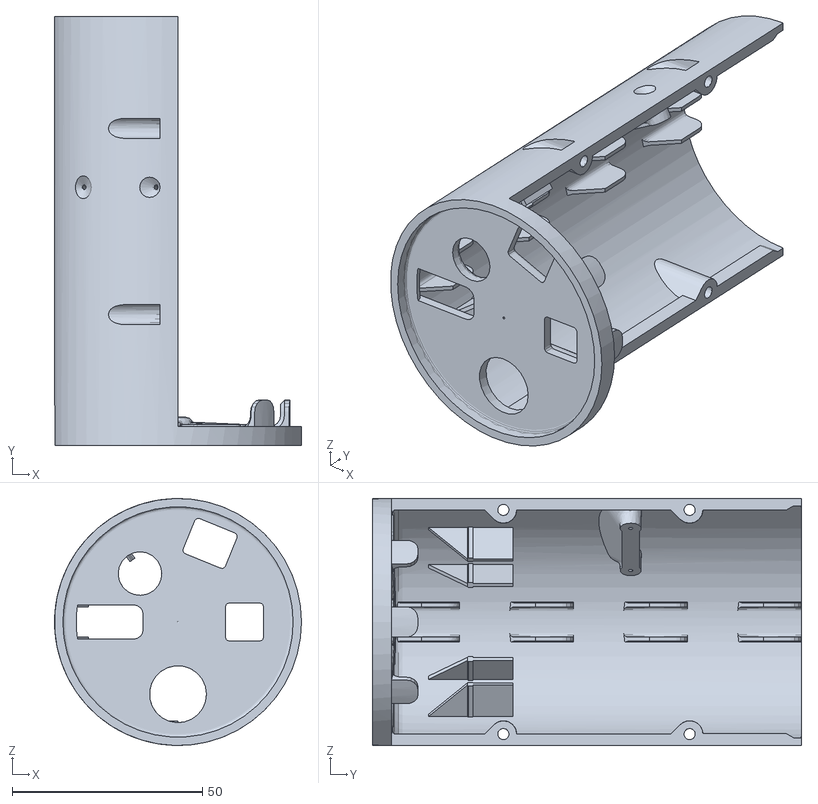
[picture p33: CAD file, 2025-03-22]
Satellite/satellite_body/vp1-v5.stl
65.0 x 113.0 x 65.0

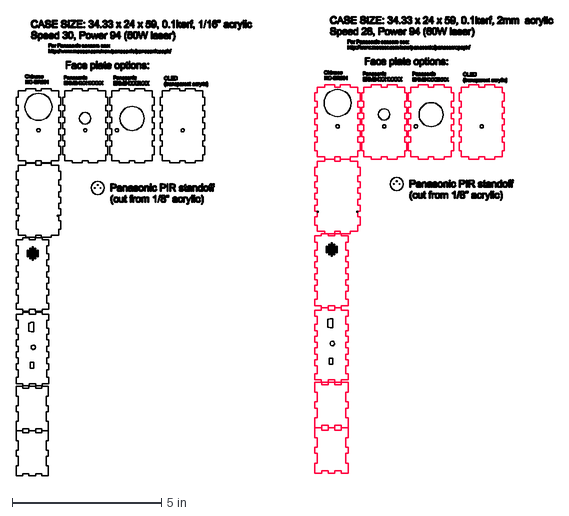
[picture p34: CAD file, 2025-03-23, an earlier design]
Electrical/RFM69HCW/RFM69-master/RFM69-master/Examples/MotionMote/OLD/LasercutCase_R3.dxf
18.0 x 15.4 in

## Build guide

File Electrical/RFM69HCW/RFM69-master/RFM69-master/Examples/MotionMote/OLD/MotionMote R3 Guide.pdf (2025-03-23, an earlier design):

## MotionMote

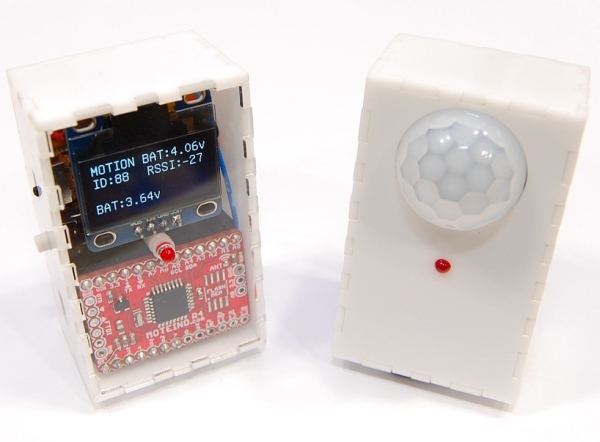
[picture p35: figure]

The wireless arduino motion sensor

MOTIONMOTE (HTTPS://LOWPOWERLAB.COM/GUIDE-CATEGORY/MOTIONMOTE/)

Overview
Kit components
Battery requirement
PIR sensor options
Assembly
Programming
Settings
Revisions & Schematic

Back to individual pages (/guide/motionmote/) (https://lowpowerlab.com/guide/motionmote/)

# Overview

This is a guide to assembling and programming and using the MotionOLED Mote Kit (https://lowpowerlab.com/shop/motionmote) into a MotionMote or into an OLEDMote. Please read the whole guide before attempting to assemble it, to avoid any errors – the assembly order matters! Familiarize yourself with the parts and their function.

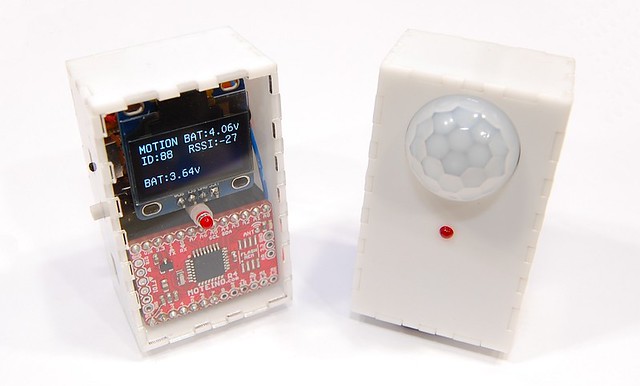
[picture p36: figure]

(https://farm4.staticickr.com/3939/15367223298_f4169eb0ab_o.jpg) (https://farm4.staticflickr.com/3939/15367223298_f4169eb0ab_o.jpg)

John’s DIY Playground overview, assembly and programming video:

Posted on September 29, 2016 (https://lowpowerlab.com/guide/motionmote/)

Privacy (https://www.google.com/intl/en/policies/privacy/) - Terms (https://www.google.com/intl/en/policies/terms/)

(https://lowpowerlab.com/)

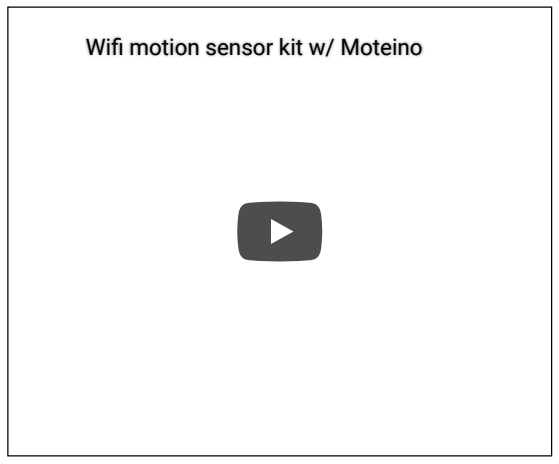
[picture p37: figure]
Wi motion sensor kit w/ Moteino

Now available in BLACK and CLEAR acrylic (upon availability/request)!
Note: for the OLEDMote variant, the front cover is always clear/transparent acrylic (to see the display).

Assembled with the ultra low power Panasonic PIR motion sensor:

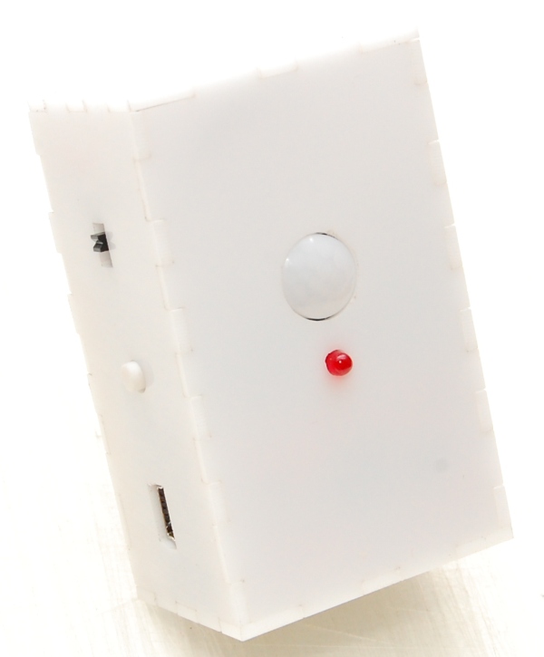
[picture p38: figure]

(https://lowpowerlab.com/wp-content/uploads/2016/09/DSC_9805.jpg)

Assembled in black acrylic with the chinese HC SR-04 motion sensor:

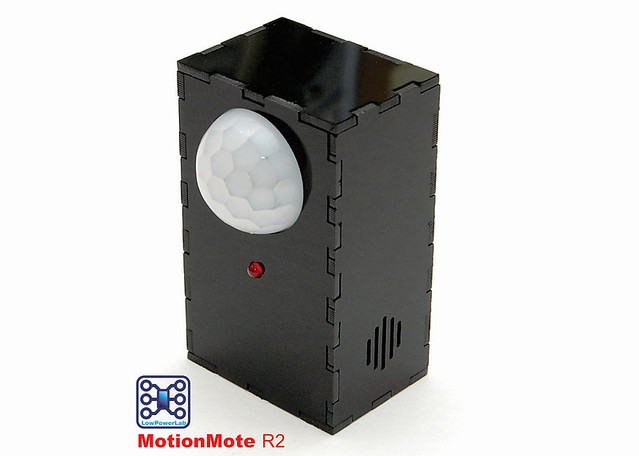
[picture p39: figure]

# Kit components

The kit (https://lowpowerlab.com/shop/motionmote) contains most of the following components, depending on whether you order a Motion or OLED version. The MotionMote comes with the PIR sensor and an acrylic front cover with a cutout for this sensor and the LED. The OLEDMote comes with the OLED (as supplies last) and with a clear acrylic front cover with a cutout only for the LED.

Sample basic kit with HC SR-04 chinese PIR sensor (white acrylic):

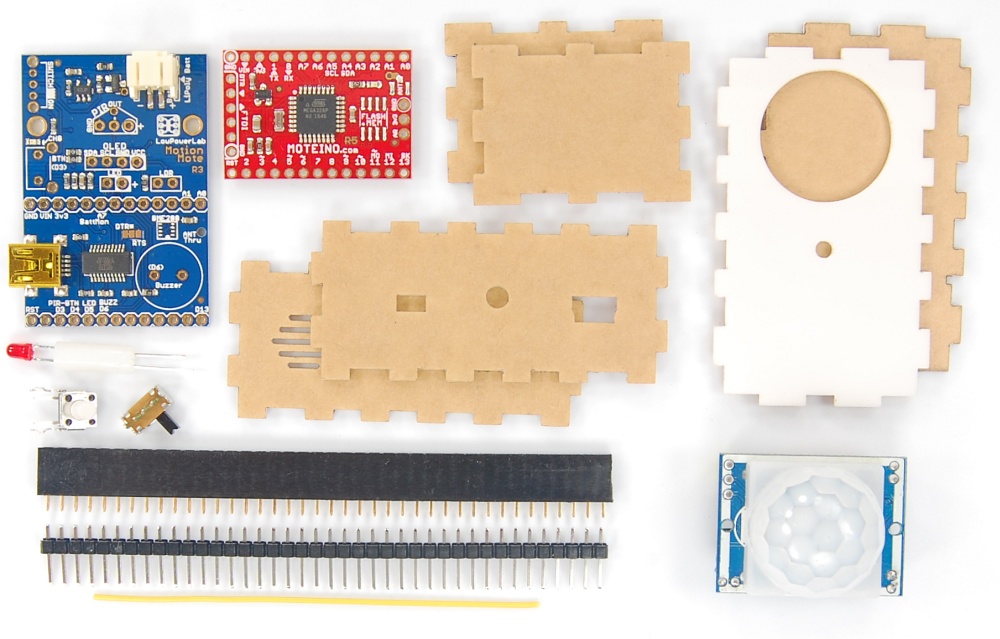
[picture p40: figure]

(https://lowpowerlab.com/wp-content/uploads/2016/09/DSC_0806.jpg)

Sample advanced kit with Panasonic ultra low power PIR sensor, BME280 atmospheric sensor, buzzer (black acrylic):

Posted on September 29, 2016 (https://lowpowerlab.com/guide/motionmote/)

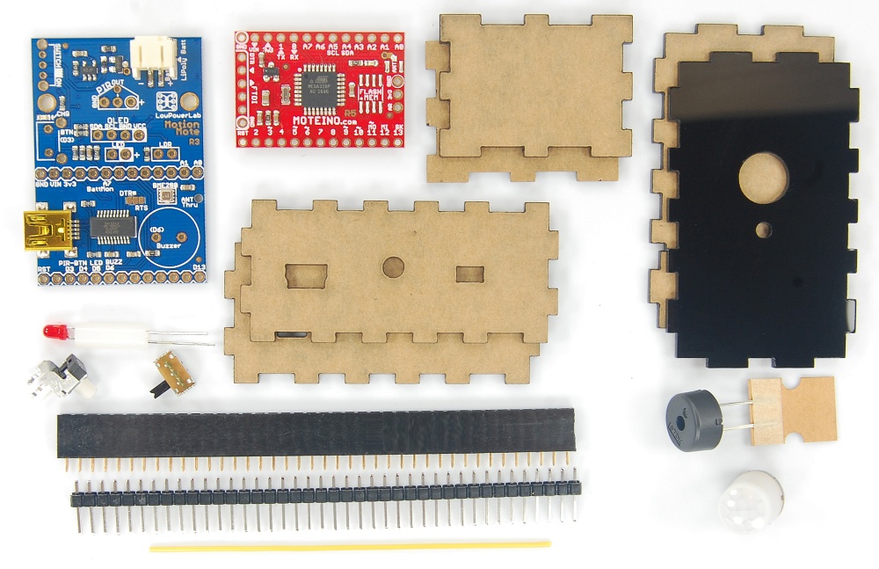
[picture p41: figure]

(https://lowpowerlab.com/wp-content/uploads/2016/09/DSC_0813.jpg)

# Battery requirement

The maximum dimensions of the Lithium Polymer battery are the following:

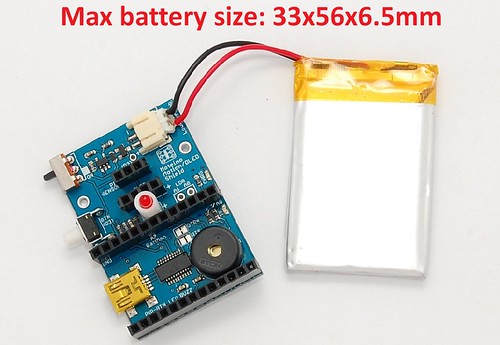
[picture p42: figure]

(https://farm6.staticickr.com/5610/15367732450_380ddb7aaa_o.jpg) (https://farm6.staticflickr.com/5610/15367732450_380ddb7aaa_o.jpg)

Charging the battery – once your kit is assembled, you can charge the battery through the onboard charger whenever you plug it in through the USB port. The charging rate is set to 212mA (R3: 4.7k charging resistor, R2: 2K resistor yields 500mA charging rate). You should use a battery that is at least 500mAh. When charging, the onboard “CHRG” LED will turn ON, and will turn OFF when the battery is fully charged. If you have an OLEDMote loaded with the default sketch (see below) it will also show the battery voltage on the screen as it charges (need to turn it ON).

# PIR sensor options

MotionMote | R3 | introduces | the | ability | to | use | ultra | low | power | Panasonic | PIR | sensors
(http://www.mouser.com/new/panasonic/panasonicpapir/). These sensors are available in several variants (WL & VZ series, 5-12m range, 1-6uA idle current). The kit offers the EKMB1201111 5m range sensor (5m range). The active detection current of this sensor is ~30uA (during motion), idle current is 2uA.

Posted on September 29, 2016 (https://lowpowerlab.com/guide/motionmote/)

Battery is not included. You will need to source your own Lithium-Polymer battery. This battery from Sparkfun (https://www.sparkfun.com/products/339) or this one from Adafruit (http://www.adafruit.com/products/1578) are good choices and will t the provided case.

Posted on September 29, 2016 (https://lowpowerlab.com/guide/motionmote/)

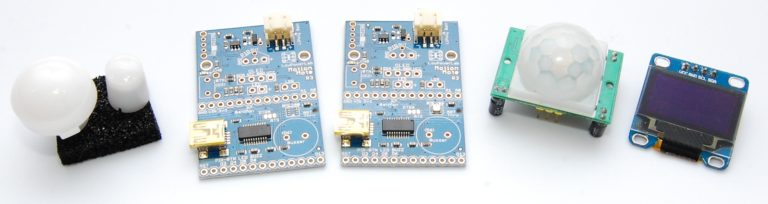
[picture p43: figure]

(https://lowpowerlab.com/wp-content/uploads/2016/08/DSC_9751.jpg)

When assembled with the Panasonic PIR, the total idle current of the unit will be around 10uA!

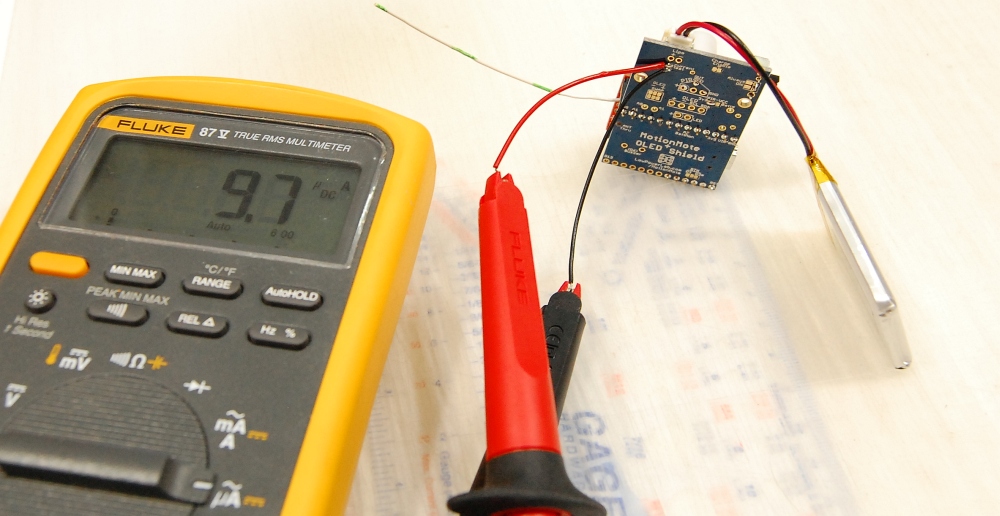
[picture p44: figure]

(https://lowpowerlab.com/wp-content/uploads/2016/09/DSC_9781.jpg)

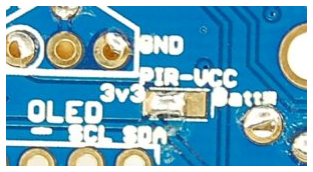
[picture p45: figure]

The default PIR motion sensor in the kit is the HC-SR501 as before. This uses around 60uA in idle, and active detection current is ~200uA.

## Hacking the HC-SR501 for lower power

The default kit PIR sensor (HC-SR501) has a supply voltage range from about 3.9V to 24V. That is great but we’re operating from a LiPo battery that runs down from 4.2V when it’s fully charged. It will still last a long time without any modications to the PIR sensor. When the battery voltage drops below 3.8-2.9V the PIR sensor will trip continuously. We don’t want that. We need the PIR sensor to work down to the 3.3V that will mark the battery discharged state. You will notice the PIR sensor has a diode and regulator.

The diode has a whopping forward voltage of 0.6V so at a minimum you will need to remove this diode. You can also short it (solder a wire to the 2 terminals of the diode.
The regulator has another 0.1-0.25V voltage drop so to get the absolute lowest voltage input range for the PIR you can remove the regulator as well (the regulator is linear so it will be very slightly inecient the higher the input voltage).

The diode (and regulator) should come off easily if you repeatedly heat the terminals. Replace them with solder bridges as shown below.

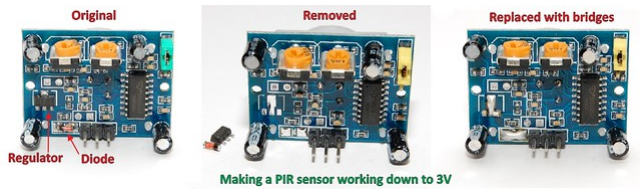
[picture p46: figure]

(https://farm4.staticickr.com/3937/15367349657_a9e68c1e7e_o.jpg) (https://farm4.staticflickr.com/3937/15367349657_a9e68c1e7e_o.jpg)

Please note that the Panasonic PIRs input voltage is 2.3-4V. For this reason, It’s recommended to use the following solder jumper to switch their VCC from battery source to 3.3V source (see the jumper options page for details):

(https://lowpowerlab.com/wp-content/uploads/2014/10/DSC_9823.jpg)

Tip for easy desoldering: these are SMD devices and could be a bit challenging to desolder if you’ve never done it before. Luckily there’s a pretty easy trick: melt a bunch of solder to your iron tip – this will increase the thermal mass of the tip. For the diode heat one side then move to the other quickly, then back and forth until the diode just comes off. If this is a really small diode (some PIRs have small some larger diodes) then you can just bridge/short the diode terminals with a small jumper wire without having to desolder it.

If you want to make the PIR even lower power, then you need to take the regulator off and bridge the regulator VIN to VOUT. With a bunch of melted solder on your iron tip, touch the 3 leads of the regulator and it should come right off, then drop the melted solder on the center and right pads where the regulator was (as seen in the photo above).

Please note: once you make these mods, the PIR will take up to 5V, and will need to be wired correctly (there is no reverse diode protection any more). This is accounted for on the MotionMote PCB so no worries there. But be careful if you ever want to use it somewhere else.

# Assembly

First, cut the headers for the Moteino from the provided female header. You will need two 1×13 (for Moteino), one 1×4 (for OLED) and 1×3 (for PIR motion sensor). See image below for how to do this correctly. Clean the cuts to make sure the header will t the case:

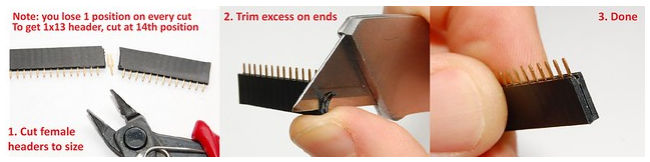
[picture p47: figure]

(https://farm4.staticickr.com/3950/15367349747_e7a5db0a39_o.jpg)Continue by soldering the headers and components (https://farm4.staticflickr.com/3950/15367349747_e7a5db0a39_o.jpg) to the main PCB in order shown in the photo below (small to large/tall). You will need to bend the pins of the switch at a 90 degree angle before soldering it. The LED is polarized! – the longer leg goes to “+” on the PCB.

If you plan to use a Panasonic PIR instead of the regular HC-SR501, do not solder the 1×3 PIR header, the sensor will instead be soldered directly to the PCB. Make sure everything is nice and ush with the PCB as this is important when putting everything in the case – when nished your PCB should look like this:

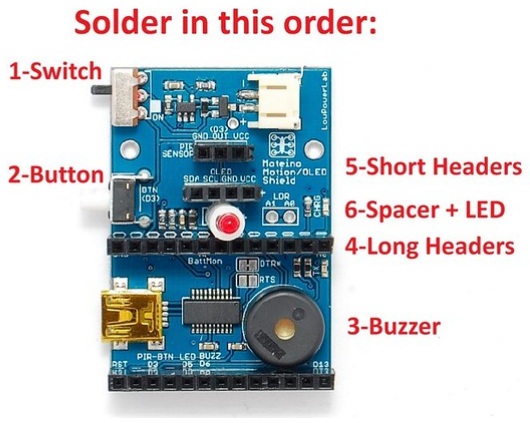
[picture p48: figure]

(https://farm4.staticickr.com/3943/14933181623_9dbcac1648_o.jpg) (https://farm4.staticflickr.com/3943/14933181623_9dbcac1648_o.jpg)

Split the male header in two 1×13 strips and solder them to the Moteino. Do not solder anything to the 1×6 FTDI header – you will program the Moteino through the USB once it is plugged into the MotionOLEDMote PCB. Also solder the antenna below the surface of the Moteino so it can be routed outside the case through the back cover (you can also keep antenna wire inside the case but performance will suffer the more wrapped it is).

Start assembling the case as sholwn below, attach battery and t all the sides together, leave the front cover last.

Posted on September 29, 2016 (https://lowpowerlab.com/guide/motionmote/)

When done soldering make sure to trim the excess leads, pins and headers on the bottom of the PCB with a ush wire cutter. The bottom should be as smooth as possible to avoid damaging the LiPo battery. You may also want to add some masking tape or thin padding between the battery and the PCB to avoid any damage.

Acrylic is brittle! Avoid putting too much pressure – use circular motions to mate two parts rather than forcing them into each other until they break. The material thickness varies between batches and making a perfect cut is impossible.

(https://farm6.staticickr.com/5614/14932605634_0204f3f7c7_o.jpg) (https://farm6.staticflickr.com/5614/14932605634_0204f3f7c7_o.jpg) (https://farm4.staticickr.com/3946/14932605584_6c330a639c_o.jpg) (https://farm4.staticflickr.com/3946/14932605584_6c330a639c_o.jpg) (https://farm (https://farm6.staticflickr.com/5604/14933181533_bfe1060c2d_o.jpg) The nal part is inserting the PIR sensor or the OLED.

Finally – t the front cover on top allowing the LED to protrude through the LED cutout. The enclosure parts are lasercut in such a way that they should t together tightly, and that may be enough to hold the case in 1 piece, but you may add clear tape to reinforce the case, this will allow taking it apart later if required. If you want, you can also permanently bond a subset or the whole case with WELD-NO #3 Acrylic Cement, this provides a strong molecular bond. When you’re done you should have something looking like this:

(https://farm4.staticickr.com/3939/15367223298_f4169eb0ab_o.jpg) (https://farm4.staticflickr.com/3939/15367223298_f4169eb0ab_o.jpg)

If you plan to use a Panasonic PIR instead of the regular HC-SR501, do not solder the 1×3 PIR header, the sensor will instead be soldered directly to the PCB. A required acrylic standoff and the correct front cover will be provided with the Panasonic PIRs if/when these will be offered in the kit. Here’s what that assembly would look like:

(https://lowpowerlab.com/wp-content/uploads/2014/10/DSC_9826.jpg) (https://lowpowerlab.com/wp-content/uploads/2014/10/DSC_9826.jpg)

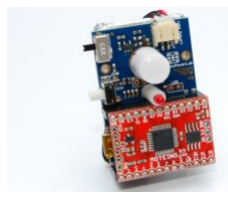
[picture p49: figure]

(https://lowpowerlab.com/wp-content/uploads/2016/08/DSC_9785.jpg) (https://lowpowerlab.com/wp-content/uploads/2016/08/DSC_9785.jpg)

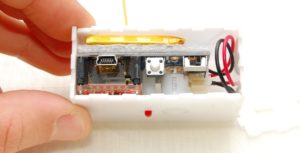
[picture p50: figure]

(https://lowpowerlab.com/wp-content/uploads/2014/10/DSC_9804.jpg) (https://lowpowerlab.com/wp-content/uploads/2014/10/DSC_9804.jpg)

(https://lowpowerlab.com/
content/uploads/2016/08 (https://lowpowerlab.com/wp-content/uploads/2016/08/DSC_9805.jpg)
- Handle the case tabs with care and don’t apply a lot of pressure.

Handle the OLED with care, the glass cover can break easily if mistreated and render the OLED screen useless. Also the acrylic cover for the cutout can break if forced too much, so handle it with care. You can always switch between them and change the sketch and change the behavior of this kit.

For the Panasonic PIRs, it’s highly recommended to use the 3.3V Moteino regulated source instead of the battery for their power input, cut the default and resolder the proper jumper like this:

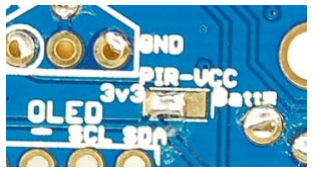
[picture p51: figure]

Lastly, the antenna wire should be peeked through the available slot on the back cover. For best signal the antenna should be kept straight rather than curled, as shown below. The cutout side slots should be set next to the buzzer and/or BME280 sensor (if any).

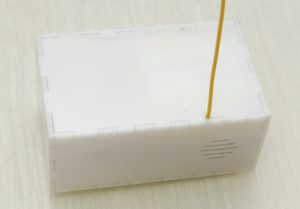
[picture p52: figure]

(https://lowpowerlab.com/wp-content/uploads/2014/10/DSC_9808.jpg)

# Programming

You will program the Moteino through the provided USB-mini port on the main PCB, once your Moteino is plugged in. When plugged in the rst time, it will act like any other FTDI device and your PC should install the driver automatically (if not, drivers are available here (http://www.ftdichip.com/FTDrivers.htm)). Then a new serial port becomes available and you can select it in Arduino IDE. Select Arduino UNO as target board. Depending on your conguration, this kit can serve as either:

a motion sensor (MotionMote sketch is here (https://github.com/LowPowerLab/RFM69/tree/master/Examples/MotionMote)). This will send a “MOTION” message to your congured receiver whenever it detects motion. This is a low power sketch that should last many months on a single charge.
a display module that shows messages on your Moteino wireless network (OLEDMote sketch is here (https://github.com/LowPowerLab/RFM69/blob/master/Examples/OLEDMote)). The provided sketch will display any messages on your network of Moteinos (same network ID, encryption key, frequency). It will also blink the LED, beep the buzzer for every received message and the side button allows you to browse through past received messages.
mailbox | notier | (http://lowpowerlab.com/motion) | (sketch | here
(https://github.com/LowPowerLab/RFM69/tree/master/Examples/MailboxNotier)). This is very similar to the MotionMote except it will not blink the LED and it will wakeup periodically to send a message indicating when motion was last detected.

These are just sample sketches that illustrate the base functionality of these modules. You can modify and customize them to t your needs.

Don’t forget that the 128x64px OLED screens can have different pin congurations, make sure to verify the pins order before you connect it to the MotionMote PCB. The default conguration is [VCC, GND, SCL, SDA], but for convenience there are jumpers on the back of MotionMote to allow swapping VCC and GND.

(https://lowpowerlab.com/wp-content/uploads/2014/10/DSC_9823.jpg)

Posted on September 29, 2016 (https://lowpowerlab.com/guide/motionmote/)

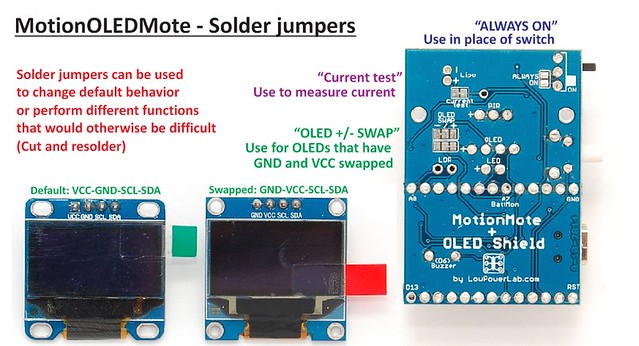
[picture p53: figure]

(https://farm6.staticickr.com/5609/15550680151_3d1205f445_o.jpg) (https://farm6.staticflickr.com/5609/15550680151_3d1205f445_o.jpg)

# Settings

The MotionOLEDMote PCB has a few solder jumpers on it. These allow you to change the current default behavior of some functions. On the front there is the [DTR]/RTS setting for FTDI (DTR is default). On the back there is a “current test” jumper that allows you to measure the current in a more convenient fashion – just cut the jumper, and solder two small wires to the 2 pads or two adjacent pin holes – these can then be hooked to your multimeter to measure current consumption. The “Always ON” jumper is open by default, but allows you to use it in place of the power switch – just solder this jumper and the battery will power the circuit at all times. The “OLED +/- swap” jumper allows you to use OLEDs that have VCC and GND swapped. See picture below that visually explains these jumpers:

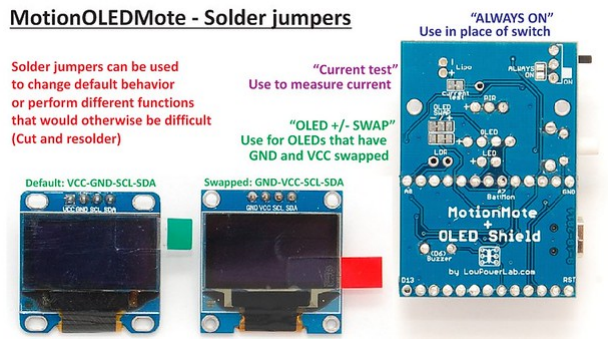
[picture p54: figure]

(https://farm6.staticickr.com/5609/15550680151_3d1205f445_o.jpg) (https://farm6.staticflickr.com/5609/15550680151_3d1205f445_o.jpg)

# Revisions & Schematic

# Revision R3

This revision had been tweaked for lower power overall. In addition it allows for Panasonic ultra low power PIR sensors (http://www.mouser.com/new/panasonic/panasonicpapir/) to be installed instead of the default chinese HC-SR501 sensors. These Panasonic sensors are much smaller and available in idle consumption as low as 1uA, although they come at a steep price. It also
features | an | optional | BME280 | (https://ae-bst.resource.bosch.com/media/_tech/media/datasheets/BST-BME280_DS001-
11.pdf)temperature/humidity/atm-pressure sensor. The power switch has changed to a much more robust part. There are some (https://ae-bst.resource.bosch.com/media/_tech/media/datasheets/BST-BME280_DS001-11.pdf) solder jumper pad changes and new jumpers that allow more exibility. The charging rate was changed to a default of 212mA (4.7K resistor). Pullups (4.7K) were added to SCL/SDA pins. An antenna through hole was added so it’s easy to route it straight to the back cover slot. A charge enable solder jumper was added – this is useful when powering from 3XAA/AAA batteries – cut it open to disable charging, resolder to re-enable it.
(https://lowpowerlab.com/wp-content/uploads/2016/08/DSC_9755.jpg)

Posted on September 29, 2016 (https://lowpowerlab.com/guide/motionmote/)

Posted on September 29, 2016 (https://lowpowerlab.com/guide/motionmote/)

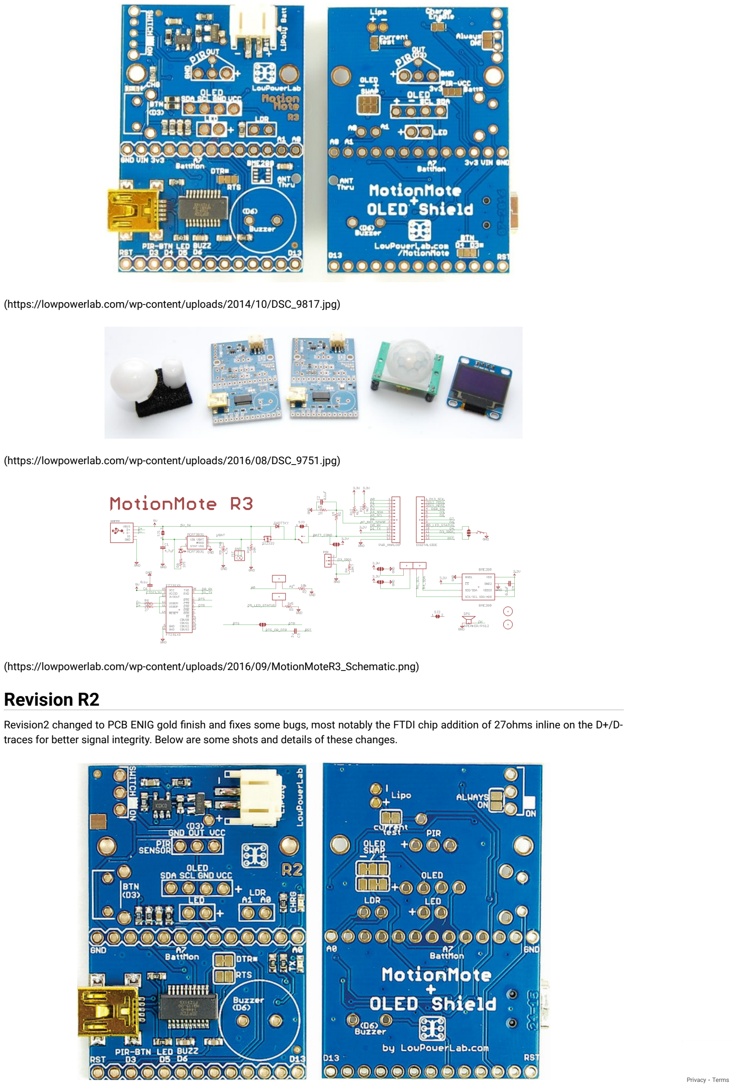
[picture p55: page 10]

(https://lowpowerlab.com/wp-content/uploads/2014/10/DSC_9817.jpg)

(https://lowpowerlab.com/wp-content/uploads/2016/08/DSC_9751.jpg)

(https://lowpowerlab.com/wp-content/uploads/2016/09/MotionMoteR3_Schematic.png)

# Revision R2

Revision2 changed to PCB ENIG gold nish and xes some bugs, most notably the FTDI chip addition of 27ohms inline on the D+/Dtraces for better signal integrity. Below are some shots and details of these changes.

(https://farm1.staticickr.com/438/19710811503_36cb297d4f_o.jpg) (https://farm1.staticflickr.com/438/19710811503_36cb297d4f_o.jpg)

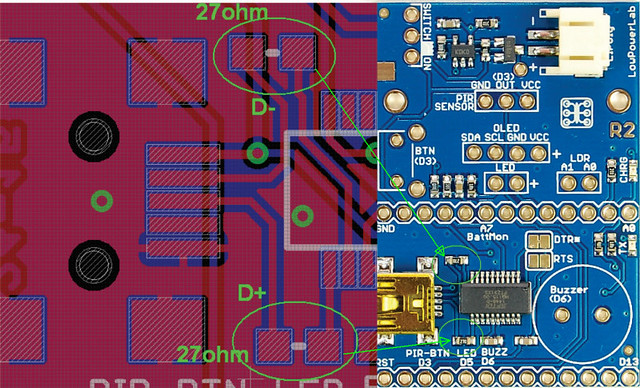
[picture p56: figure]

(https://farm1.staticickr.com/508/20143691178_2a9f550f95_o.jpg) (https://farm1.staticflickr.com/508/20143691178_2a9f550f95_o.jpg)

Related Products

MotionMote Kit
Buy: $24.95
(http://lowpowerlab.com/shop/product/114)

PIR motion sensor
Buy: $5.00
(http://lowpowerlab.com/shop/product/113)

Moteino
Buy: $13.95
(http://lowpowerlab.com/shop/product/99)

FTDI Adapter
Buy: $14.95
(http://lowpowerlab.com/shop/product/90)

Low power LED (3mm)
Buy: $0.25
(http://lowpowerlab.com/shop/product/102)

Piezo Buzzer
Buy: $1.50
(http://lowpowerlab.com/shop/product/124)

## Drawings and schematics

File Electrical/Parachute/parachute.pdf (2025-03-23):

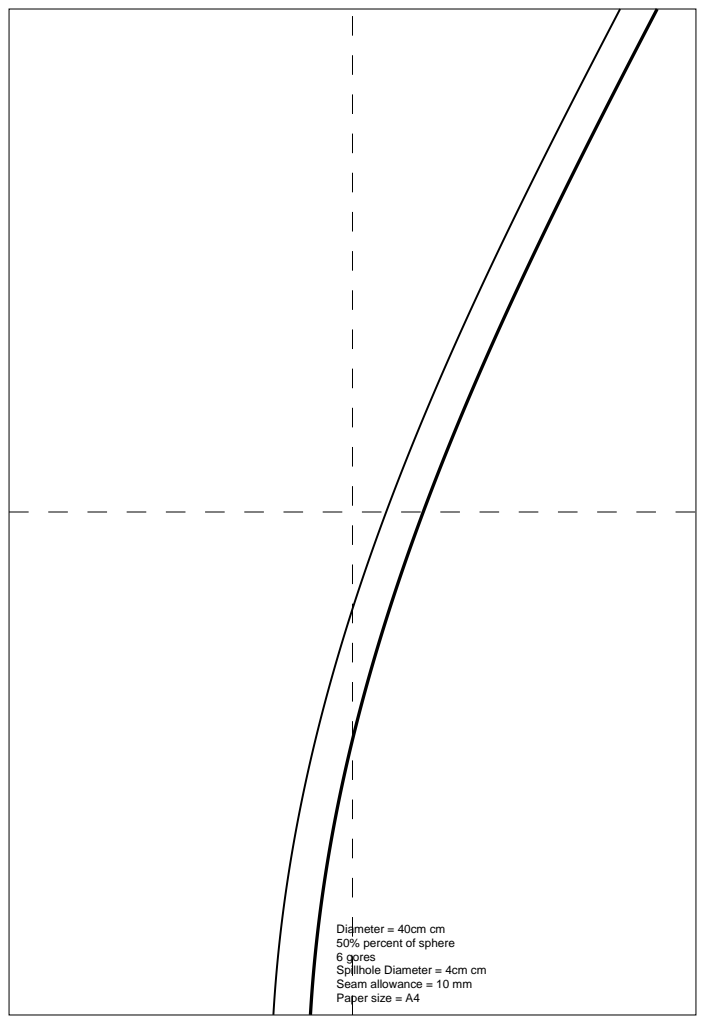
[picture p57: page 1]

Diameter = 40cm cm
50% percent of sphere
6 gores
Spillhole Diameter = 4cm cm
Seam allowance = 10 mm
Paper size = A4

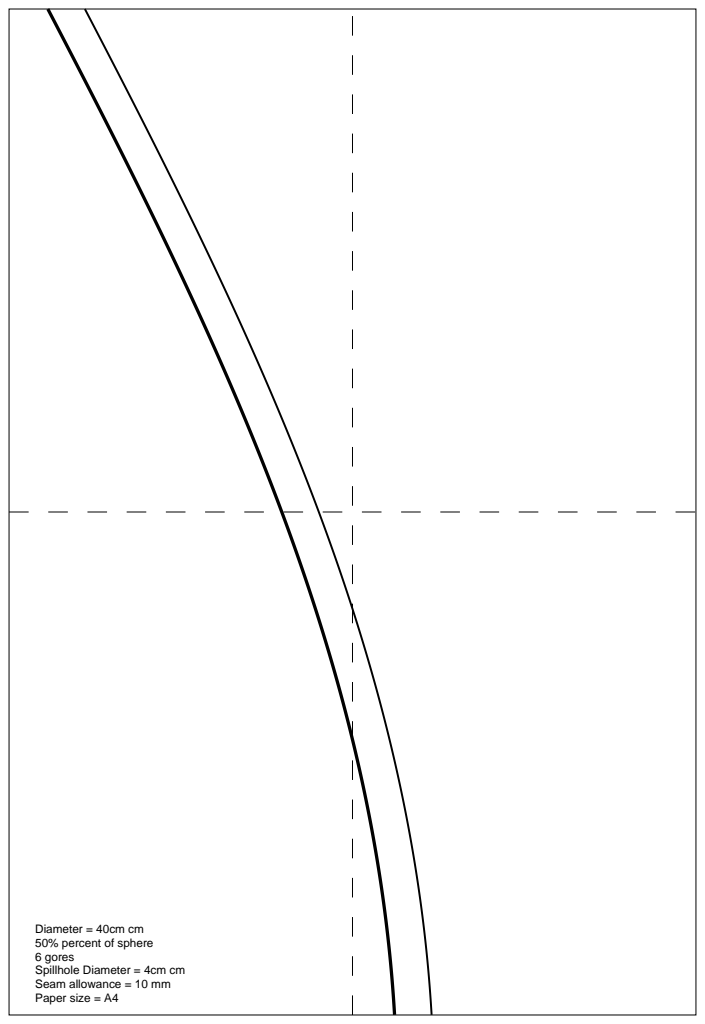
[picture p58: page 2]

Diameter = 40cm cm
50% percent of sphere
6 gores

Seam allowance = 10 mm
Paper size = A4

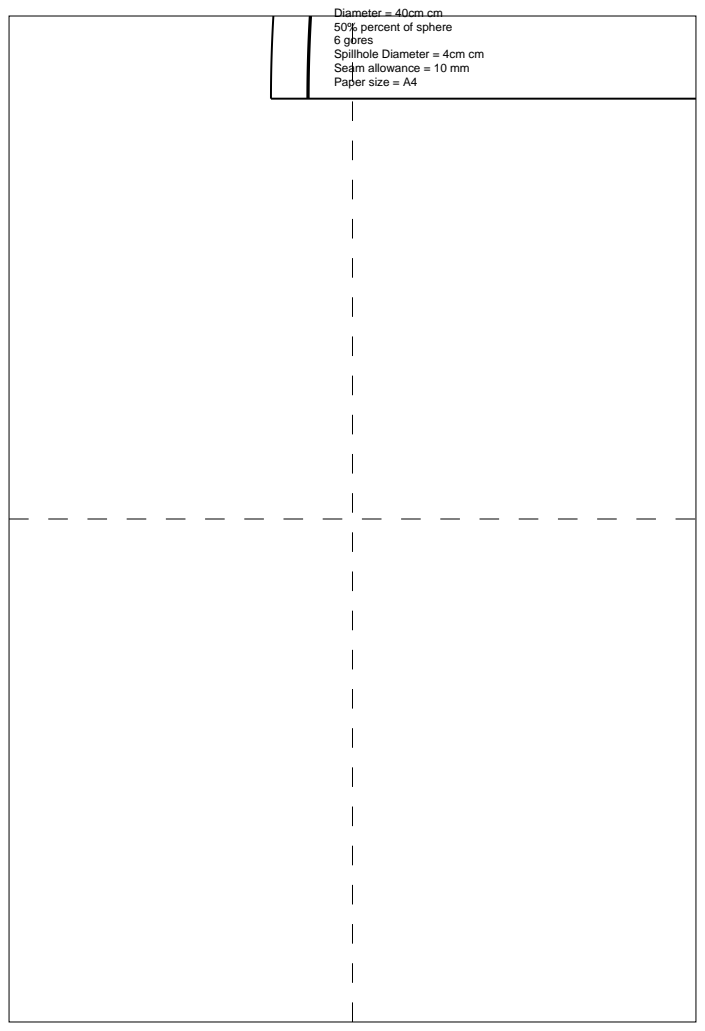
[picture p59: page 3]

Diameter = 40cm cm
50% percent of sphere
6 gores

Seam allowance = 10 mm
Paper size = A4

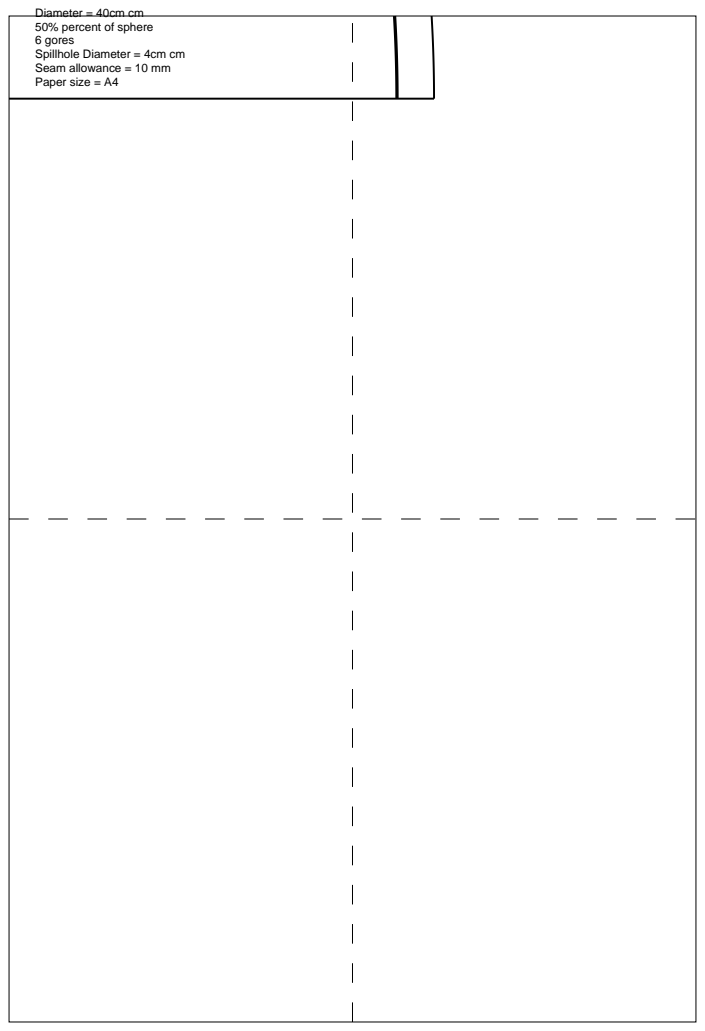
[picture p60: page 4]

Diameter = 40cm cm
50% percent of sphere
6 gores

Seam allowance = 10 mm
Paper size = A4

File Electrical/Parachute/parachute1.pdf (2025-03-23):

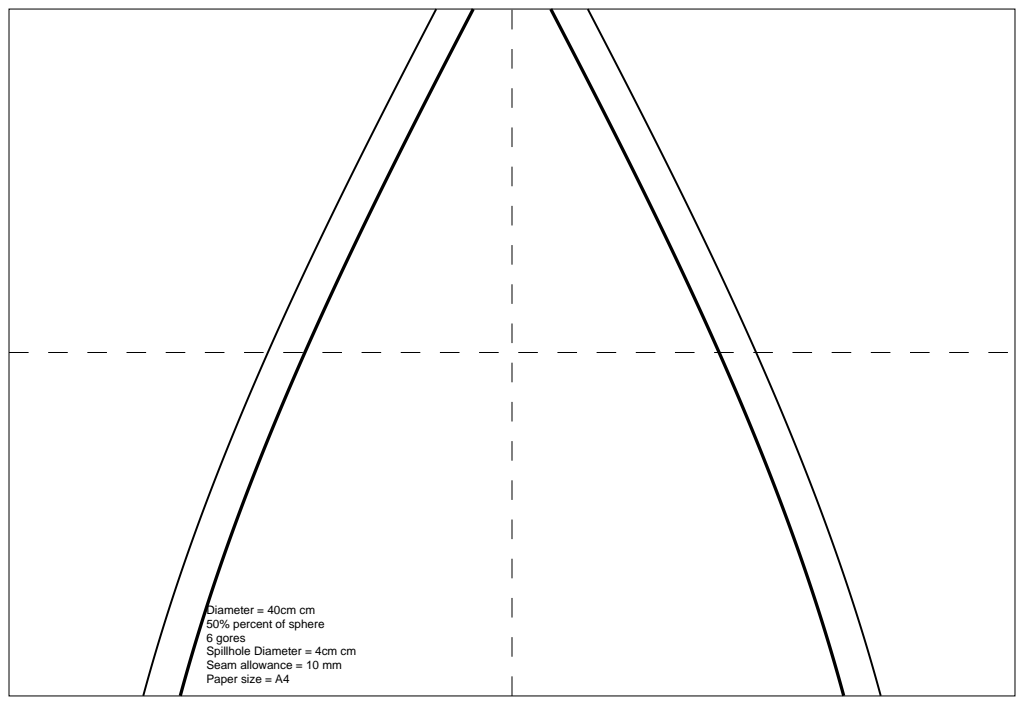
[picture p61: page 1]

Diameter = 40cm cm
50% percent of sphere
6 gores
Spillhole Diameter = 4cm cm
Seam allowance = 10 mm
Paper size = A4

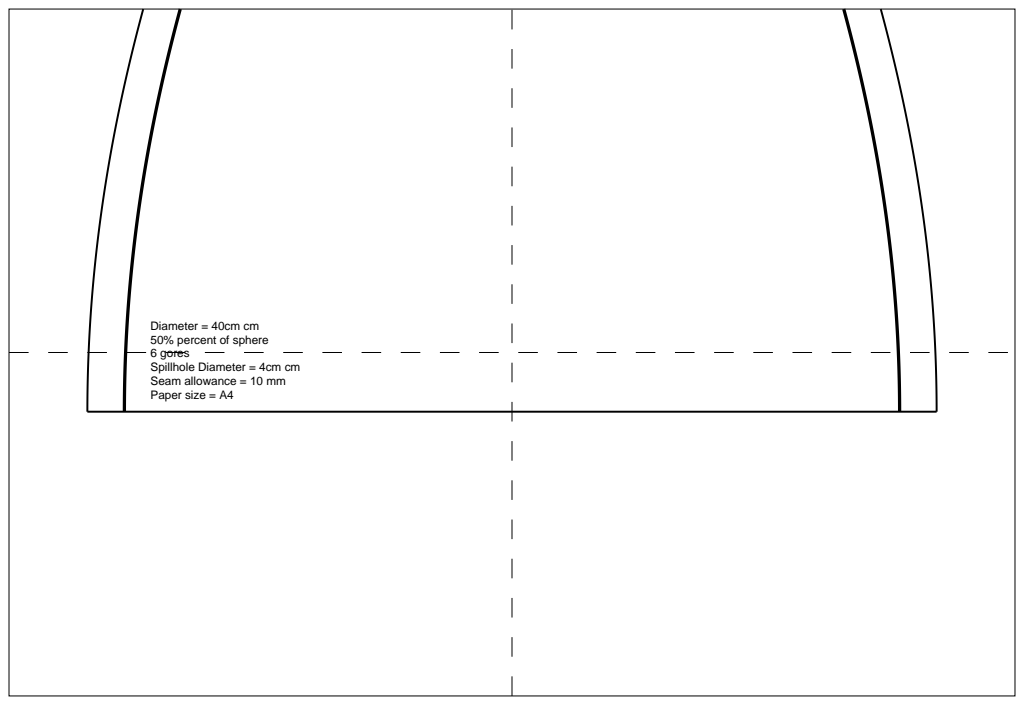
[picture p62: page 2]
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

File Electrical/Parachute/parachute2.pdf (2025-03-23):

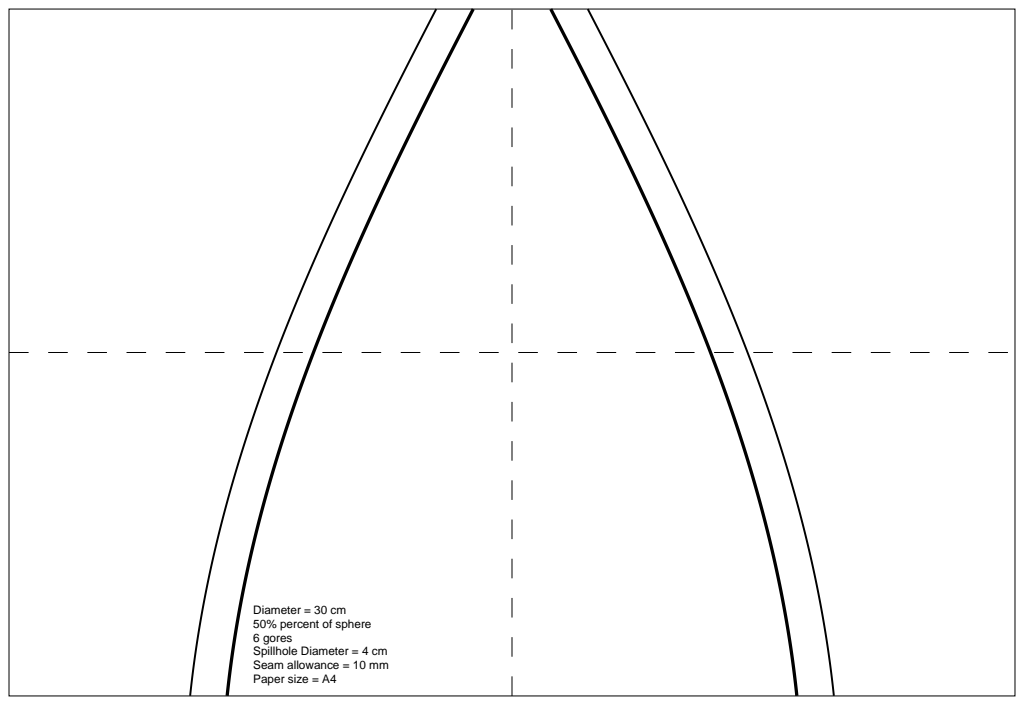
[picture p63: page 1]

Diameter = 30 cm
50% percent of sphere
6 gores
Spillhole Diameter = 4 cm
Seam allowance = 10 mm
Paper size = A4

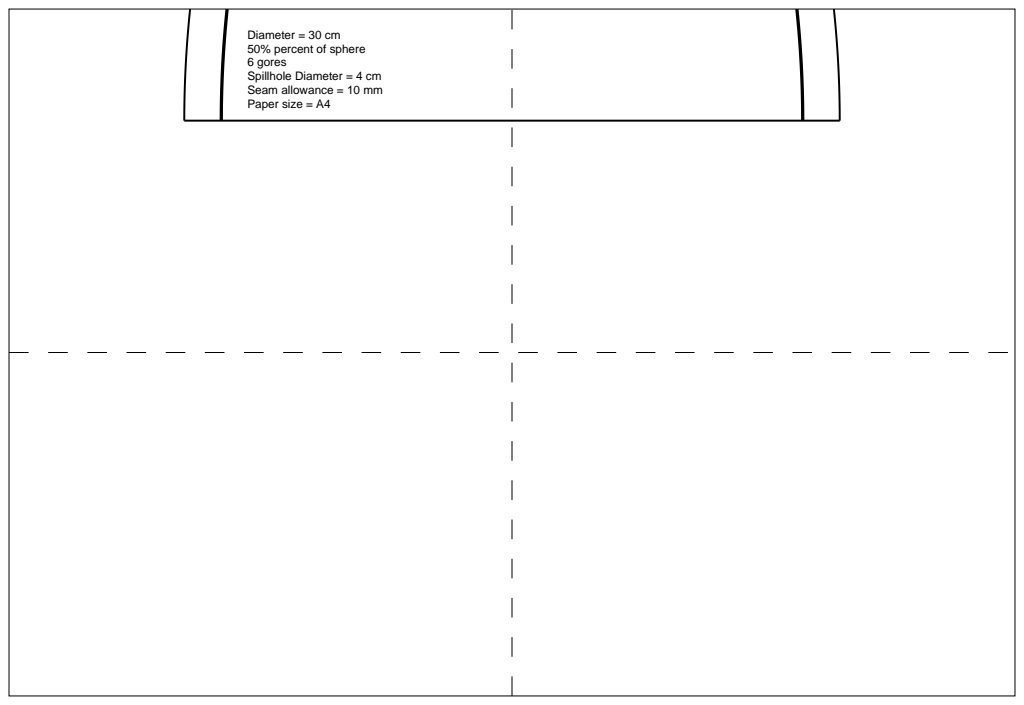
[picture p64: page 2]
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

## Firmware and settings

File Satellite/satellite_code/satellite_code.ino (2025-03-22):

#include <Wire.h>
#include <SPI.h>
#include <Adafruit_BMP280.h>
#include <RH_RF69.h>
#include <SD.h>
#include <DFRobot_GNSS.h>
#include <Adafruit_MPU6050.h>
#include <Adafruit_Sensor.h>

// specify pins
#define BMP_SCK     (13)
#define BMP_MISO    (12)
#define BMP_MOSI    (11)
#define BMP_CS      (10)

#define RFM69_CS    6
#define RFM69_INT   9
#define RFM69_RST   10
#define RADIO_LED   13

// set radio frequency
#define RF69_FREQ   867500000

const int chipSelect = 4;
int32_t packetnum = 0;

Adafruit_BMP280 bmp;
Adafruit_MPU6050 mpu;

RH_RF69 rf69(RFM69_CS, RFM69_INT);
DFRobot_GNSS_I2C gnss(&Wire ,GNSS_DEVICE_ADDR);

void setup() {
  Serial.begin(9600);

  // initialise modules
  init_radio_module();
  init_bmp_module();
  init_mpu_module();
  init_mq_module();
  init_sd_card();
  init_gnss_module();
}

void loop() {
  unsigned long ms = millis();

  String dataString = "";

  sensors_event_t a; // m / s^2
  sensors_event_t g; // rad / s
  sensors_event_t temp; // C

  mpu.getEvent(&a, &g, &temp);

  sTim_t date = gnss.getDate(); // Date
  sTim_t utc = gnss.getUTC(); // UTC Time
  sLonLat_t lat = gnss.getLat(); // Latitude
  sLonLat_t lon = gnss.getLon(); // Longitude
  double high = gnss.getAlt(); // Altitude - m
  double cog = gnss.getCog(); // Course over Ground - Degrees
  double sog = gnss.getSog() * 0.514; // Speed over Ground - m / s

  float temperature = bmp.readTemperature(); // C
  float pressure = bmp.readPressure() / 100; // hPa
  float altitude = bmp.readAltitude(1013.25); // m
  float airquality = analogRead(11); // PPM

  float gforce = sqrt((a.acceleration.x * a.acceleration.x) + (a.acceleration.y * a.acceleration.y) + (a.acceleration.z * a.acceleration.z)) - 11;
  // after testing we found that during a state of rest the sensor measured 11G's, so we removed the constant positive G-Force to maintain correct data measurement 

  // save data to SD card and format lines for data recovery and Serial Studio handling
  dataString += String(packetnum, DEC);
  dataString += ",";
  dataString += String(date.year);
  dataString += "/";
  dataString += String(date.month);
  dataString += "/";
  dataString += String(date.date);
  dataString += ",";
  dataString += String(utc.hour);
  dataString += ":";
  dataString += String(utc.minute);
  dataString += ":";
  dataString += String(utc.second);
  dataString += ",";
  dataString += String(lat.latitudeDegree, 6);
  dataString += ",";
  dataString += String(lon.lonitudeDegree, 6);
  dataString += ",";
  dataString += String(high, 1);
  dataString += ",";
  dataString += String(cog, 2);
  dataString += ",";
  dataString += String(sog, 2);
  dataString += ",";
  dataString += String(temperature, 1);
  dataString += ",";
  dataString += String(pressure, 1);
  dataString += ",";
  dataString += String(airquality, 0);
  dataString += ",";
  dataString += String(a.acceleration.x);
  dataString += ",";
  dataString += String(a.acceleration.y);
  dataString += ",";
  dataString += String(a.acceleration.z);
  dataString += ",";
  dataString += String(g.gyro.x);
  dataString += ",";
  dataString += String(g.gyro.y);
  dataString += ",";
  dataString += String(g.gyro.z);
  dataString += ",";
  dataString += String(gforce, 1);
  dataString += ";";

  File dataFile = SD.open("datalog.txt", FILE_WRITE);

  if (dataFile) {
    dataFile.println(dataString);
    dataFile.close();
  }

  // send and format telemetry data to Ground Station
  String packet_str = "";
  packet_str.concat(String(String(packetnum, DEC) + ","));
  packet_str.concat(String(lat.latitudeDegree, 6) + ",");
  packet_str.concat(String(lon.lonitudeDegree, 6) + ",");
  packet_str.concat(String(high, 1) + ";");

  rf69.send((uint8_t *)(packet_str.c_str()), packet_str.length());
  rf69.waitPacketSent();

  uint8_t buf[5];
  uint8_t len = sizeof(buf);

  if (rf69.waitAvailableTimeout(10))  { 
    if (rf69.recv(buf, &len)) {
        Serial.print(": ");
        Serial.println((char*)buf);
        Blink(RADIO_LED, 10, 1);
    } else {
        Serial.println("Receive failed");
        Serial.println();
        Blink(RADIO_LED, 10, 2);
    }
  } else {
      Serial.println("No reply, is another RFM69 listening?");
      Serial.println();
      Blink(RADIO_LED, 10, 3); 
  }

  packetnum += 1;
  delay(100);
}

void init_radio_module() {
  pinMode(RADIO_LED, OUTPUT);     
  pinMode(RFM69_RST, OUTPUT);
  digitalWrite(RFM69_RST, LOW);

  digitalWrite(RFM69_RST, HIGH);
  delay(10);
  digitalWrite(RFM69_RST, LOW);
  delay(10);
  
  rf69.init();
  rf69.setFrequency(RF69_FREQ)
  rf69.setTxPower(16, true); // power range: 14 - 20

  uint8_t key[] = {
                    0x01, 0x02, 0x03, 0x04, 0x05, 0x06, 0x07, 0x08,
                    0x01, 0x02, 0x03, 0x04, 0x05, 0x06, 0x07, 0x08
                  };
  rf69.setEncryptionKey(key);
  
  pinMode(RADIO_LED, OUTPUT);
}

void init_bmp_module() {
  unsigned status;

  status = bmp.begin();
  bmp.setSampling(
                  Adafruit_BMP280::MODE_NORMAL,     
                  Adafruit_BMP280::SAMPLING_X2,     
                  Adafruit_BMP280::SAMPLING_X16,   
                  Adafruit_BMP280::FILTER_X16,      
                  Adafruit_BMP280::STANDBY_MS_500
                );
}

void init_gnss_module() {
  gnss.begin();
  gnss.enablePower(); 
  gnss.setGnss(eGPS_BeiDou_GLONASS); 
  gnss.setRgbOn();
}

void init_mpu_module() {
  mpu.begin();
  // setting sensor ranges
  mpu.setAccelerometerRange(MPU6050_RANGE_16_G);
  mpu.setGyroRange(MPU6050_RANGE_2000_DEG);
  mpu.setFilterBandwidth(MPU6050_BAND_21_HZ);
}

void init_mq_module() {
  pinMode(11, INPUT);
}

void init_sd_card() {
  SD.begin(chipSelect);
}

void Blink(byte pin, byte delay_ms, byte loops) {
  while (loops--) {
    digitalWrite(pin, HIGH);
    delay(delay_ms);
    digitalWrite(pin, LOW);
    delay(delay_ms);
  }
}

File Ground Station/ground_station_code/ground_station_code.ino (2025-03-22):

#include <SPI.h>
#include <RH_RF69.h>

// set radio frequency
#define RF69_FREQ     867500000

// specify pins
#define RFM69_CS      6
#define RFM69_INT     9
#define RFM69_RST     10
#define LED           13

RH_RF69 rf69(RFM69_CS, RFM69_INT);

int32_t packetnum = 0; // packet counter

void setup() {
  Serial.begin(9600);

  init_radio_module();
}

void loop() {
 if (rf69.available()) { 
    uint8_t buf[50];
    uint8_t len = sizeof(buf);

    if (rf69.recv(buf, &len)) {
      if (!len) return;

      // print received data with added RSSI value
      buf[len] = 0;

      Serial.print("$");
      Serial.print(rf69.lastRssi(), DEC);
      Serial.print(",");
      Serial.print((char*)buf);
      Serial.print("\r\n");

      // send reply
      uint8_t data[] = "ACK";

      rf69.send(data, sizeof(data));
      rf69.waitPacketSent();

      Blink(LED, 50, 1);
    }
  }
}

void Blink(byte PIN, byte DELAY_MS, byte loops) {
  for (byte i = 0;i < loops; i++)  {
    digitalWrite(PIN,HIGH);
    delay(DELAY_MS);
    digitalWrite(PIN,LOW);
    delay(DELAY_MS);
  }
}

void init_radio_module() {
  pinMode(LED, OUTPUT);     
  pinMode(RFM69_RST, OUTPUT);
  digitalWrite(RFM69_RST, LOW);

  digitalWrite(RFM69_RST, HIGH);
  delay(10);
  digitalWrite(RFM69_RST, LOW);
  delay(10);

  rf69.init();
  rf69.setFrequency(RF69_FREQ);
  rf69.setTxPower(16, true);  // power range: 14 - 20

  uint8_t key[] = { 
                    0x01, 0x02, 0x03, 0x04, 0x05, 0x06, 0x07, 0x08,
                    0x01, 0x02, 0x03, 0x04, 0x05, 0x06, 0x07, 0x08
                  };
  rf69.setEncryptionKey(key);
  
  pinMode(LED, OUTPUT);
}
